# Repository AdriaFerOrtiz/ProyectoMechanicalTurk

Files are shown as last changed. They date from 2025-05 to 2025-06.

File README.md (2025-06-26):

# MechanicalTurk  
*A modern robotic chess player inspired by the historical "Mechanical Turk," combining computer vision, cloud-based AI, and precision robotics to play chess autonomously.*  

---

## 🎯 Project Description  
**MechanicalTurk-ChessRobot** is an autonomous chess-playing robot that bridges physical and digital gameplay. It uses a **cartesian robotic system** to move pieces on a physical board, guided by:  
- **Computer Vision**: Detects piece positions via a camera.  
- **Cloud AI**: Leverages Stockfish or Leela Chess Zero for move calculations.  
- **Precision Robotics**: Moves pieces magnetically from beneath the board.  

**Key Features**:  
- Plays against humans or acts as a physical proxy for online games.  
- Handles edge cases like **obstacle avoidance** (e.g., moving blocking pieces temporarily).  
- **Web interface** to play remotely (like Chess.com but with a real robot).  

**Example Scenario**:  
> A user makes a move on the physical board → The robot’s camera captures the move → Cloud AI calculates the best response → The robot moves the piece by performing the movement intended by the AI.  

---

## 📽️ Demo  

[Video of the robot in action](https://drive.google.com/file/d/1c9VE16P7BDXVjnB_LtAGnboGmgiGng_8/view?usp=drive_link )

---

## 📖 Table of Contents  
1. [Installation](#installation)
   - [Google Cloud Plataform (GCP)](#-1-google-cloud-platform-gcp)
   - [Local Robot Sofrware](#2-local-software)
2. [Electrical Wiring Diagram](#electrical-wiring-diagram)
3. [Components](#components)  
4. [Hardware Design](#hardware-design)  
5. [Software Architecture](#software-architecture)  
   - [Cloud Infrastructure (Google Cloud)](#1-cloud-infrastructure-google-cloud)  
   - [Local Robot Software](#-2-local-robot-software)
   - [Chessboard and Piece Recognition Using Computer Vision](#3-chessboard-and-piece-recognition-using-computer-vision)
6. [3D components](#3d-components)  
7. [Contributions](#amazing-contributions)  
8. [Authors](#authors)  

---

## Installation

This project is composed of two main components:

1. 🌐 The **Google Cloud** infrastructure, which handles vision and chess engine logic.
2. 🤖 The **local robot software**, which controls physical movements and logic.

---

### 🌐 1. Google Cloud Platform (GCP)

#### 📁 Project structure

In the `Google-Cloud/` directory, you will find:

* `chessboard_model/`: (Not required for installation) Training code for the original vision model.
* `chessboard_visual_function/`: Code used in the **Cloud Function** for detecting the board and pieces from an image.
* `chessboard_web/`: Frontend code and Firebase project. Contains:

  * `public/`: The web app (`index.html`, `script.js`, `styles.css`).
* `stockfish_cloud_run/`: Code for deploying **Stockfish** to **Cloud Run**.

#### ☁️ Google Cloud Setup

Make sure you have the Google Cloud CLI installed and authenticated:

```bash
gcloud auth login
gcloud config set project [YOUR_PROJECT_ID]
```

##### 🔸 Deploy the Vision Cloud Function

Go to the folder:

```bash
cd Google-Cloud/chessboard_visual_function
```

Deploy the function:

```bash
gcloud functions deploy predict_chessboard \
  --runtime python310 \
  --trigger-http \
  --allow-unauthenticated \
  --region europe-southwest1 \
  --entry-point predict_chessboard
```

##### 🔸 Deploy Stockfish on Cloud Run

From the folder:

```bash
cd Google-Cloud/stockfish_cloud_run
```

Deploy with:

```bash
gcloud run deploy stockfish-service \
  --source . \
  --allow-unauthenticated \
  --region europe-west1
```

##### 🔸 Web Setup (Firebase Hosting)

You can test the web from the `public/` folder using any static server:

```bash
cd Google-Cloud/chessboard_web/public
python3 -m http.server 8000
# Or open index.html manually in your browser
```

If you have Firebase CLI configured and wish to deploy:

```bash
cd Google-Cloud/chessboard_web
firebase deploy
```

> ⚠️ Remember to update the endpoints in `script.js` with your actual deployed URLs for:
>
> * `predict_chessboard`
> * `stockfish-service`

---

### 2. Local Software

#### 📁 Project location

The local code is in the `src/` folder and includes:

* `modulo_central.py`: Handles logic and piece coordination.
* `motor_control.py`: Translates paths into robot movement commands.
* `game_state.py`: Board representation and utilities.
* `conexion_web.py`: A simulated Flask server to receive move commands.

#### ✅ Requirements

Since there's no `requirements.txt`, you can install the necessary packages with:

```bash
pip install flask flask-cors requests serial
```

If needed, here’s a `requirements.txt` you can create inside `src/`:

```txt
flask
flask-cors
requests
serial
```

#### 🚀 Running the robot server

Launch the Flask server to allow robot communication:

```bash
cd src
python conexion_web.py
```

This server listens on port `5000` and logs moves received from the web interface.

---
## Electrical Wiring Diagram

The following diagram illustrates the complete wiring of the robot's electronic components, including the Arduino, stepper drivers, relays, power supply, and camera system:

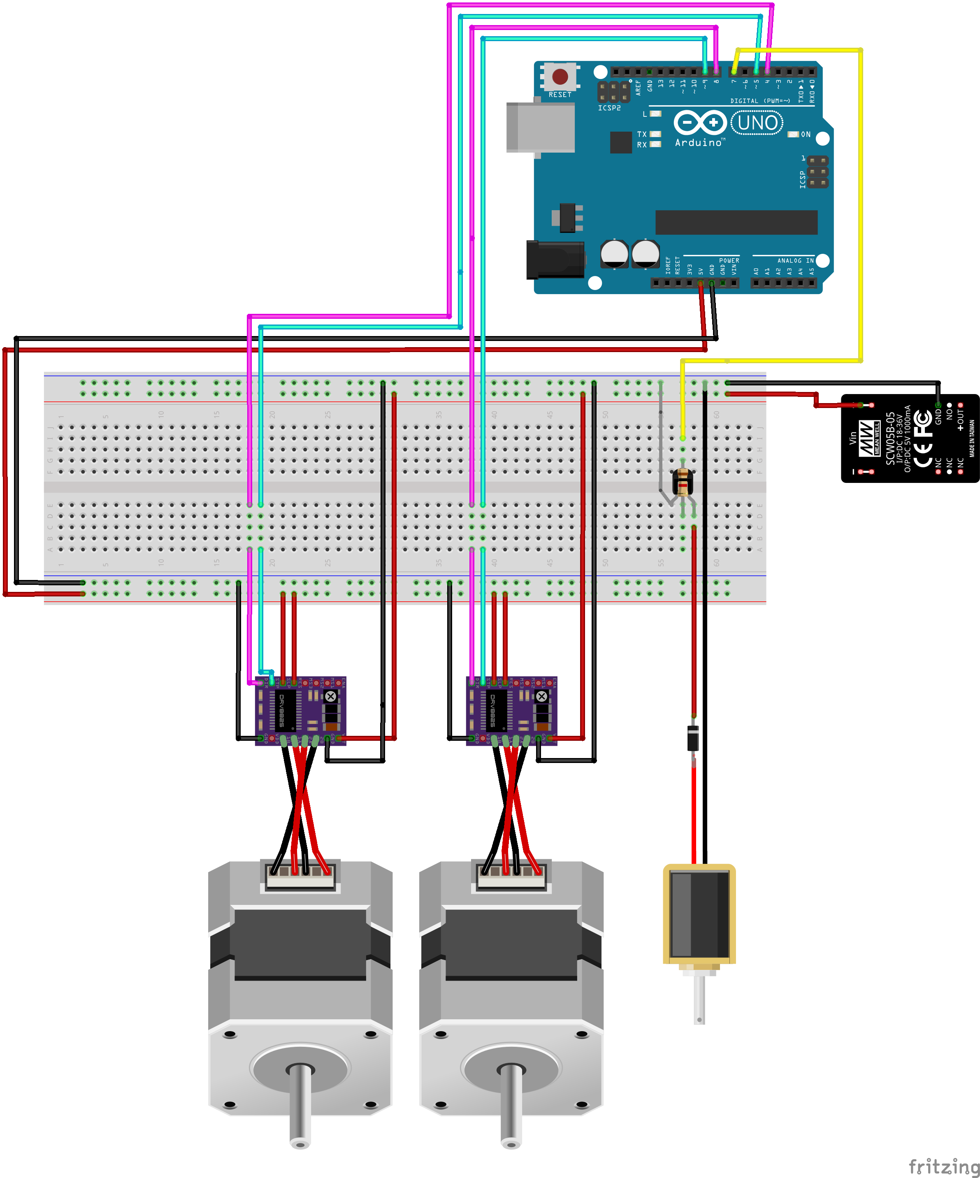
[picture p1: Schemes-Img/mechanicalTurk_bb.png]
Wiring Diagram


## Components
| Componente | Imagen | Enlace |
|---|---|---|
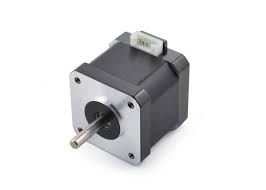
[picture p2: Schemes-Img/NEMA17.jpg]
NEMA17
| **Motor NEMA 17 / 3.5 Kg** |  | [Bricogeek](https://tienda.bricogeek.com/motores-paso-a-paso/1360-motor-nema-17-35kg-con-conector-y-cable.html) |
| **Arduino Uno** | Arduino Uno | [Arduino.cc](https://store.arduino.cc/products/arduino-uno-rev3) |
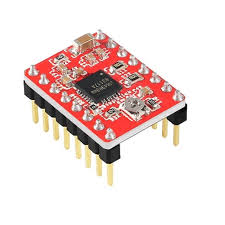
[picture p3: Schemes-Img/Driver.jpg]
A4988
| **Driver A4988** |  | [Pololu](https://www.pololu.com/product/1182) |
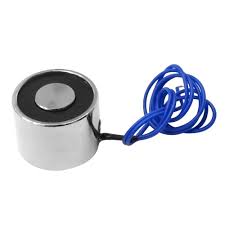
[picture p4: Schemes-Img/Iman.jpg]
12V Electroimán
| **Electroimán 12 V / 100 N** |  | [TodoElectrónica](https://www.todoelectronica.com/modulo-rele-5vdc-de-1-canal-10a-para-arduino-p-110226.html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)  |
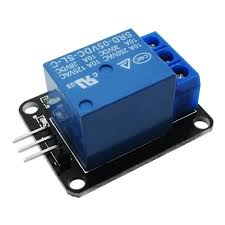
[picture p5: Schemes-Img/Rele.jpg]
Relé 5V 10A
| **Relé 5 V 10 A** |  | [Amazon](https://www.amazon.com/10A-Channel-Relay-Module-Arduino/dp/B07Z432CS3) |
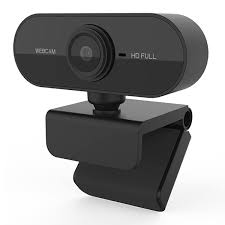
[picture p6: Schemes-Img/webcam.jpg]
Webcam Genérica
| **Webcam USB Genérica (720p/1080p)** |  | [Amazon – Webcam USB 1080p con micrófono](https://www.amazon.com/-/es/Webcam-Computadora-Micrófono-Resolución-Streaming/dp/B08HRPDYTP) |
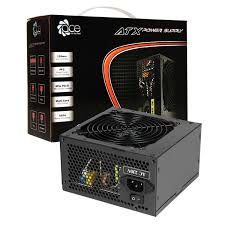
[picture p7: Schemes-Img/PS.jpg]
ATX PSU
| **ATX 500W Power Supply** |  | [PCComponentes (similar)](https://www.pccomponentes.com/fuentes-de-alimentacion) |
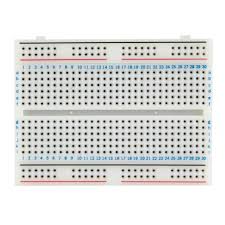
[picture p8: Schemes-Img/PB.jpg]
ProtoBoard
| **456 Point Breadboard** |  | [Amazon](https://www.amazon.com/EL-CP-003-Breadboard-Distribution-Solderless-Prototyping/dp/B01EV6LJ7G) |

**Software**:  
- **Google Cloud Vision** (Computer vision)  
- **Stockfish 16** (Chess engine)  
- **FastAPI** (Web interface backend)  

---

## Hardware Design
*Cartesian robot design.*  

Hardware movement gif

---

## Software Architecture

### 1. Cloud Infrastructure (Google Cloud)

This project leverages **Google Cloud Platform (GCP)** to handle compute-intensive tasks such as board recognition and AI move generation. The cloud infrastructure is composed of two key services:

#### 🔍 Cloud Function: Board Recognition

A **Cloud Function** receives chessboard images captured via webcam or uploaded through the web interface. These images are processed using a trained machine learning model (TensorFlow or PyTorch), and the function returns a board state encoded as an 8x8 matrix in FEN-like notation.

* **Input:** JPEG or PNG image of the board
* **Output:** JSON object containing the current board state

#### ♟️ Cloud Run: Stockfish

A **Cloud Run** container hosts a persistent instance of the **Stockfish chess engine**. It takes the current board state and returns:

* The best move according to Stockfish (UCI notation)
* The evaluation score of the position (e.g., `+0.8`, `Mate in 2`)

#### 🌐 Web-to-Cloud Communication

The frontend web app communicates with these cloud services:

* Image uploads → sent to the Vision Cloud Function
* Board state → sent to the Stockfish Cloud Run service

#### 🖥️ Web Interface Overview

The web application acts as the **central control panel** for the system. It provides:

* Upload and processing of board images
* A real-time digital rendering of the chessboard
* The ability to play against another human or Stockfish
* Visualization of Stockfish evaluations and suggested moves
* Communication with the robot via HTTP

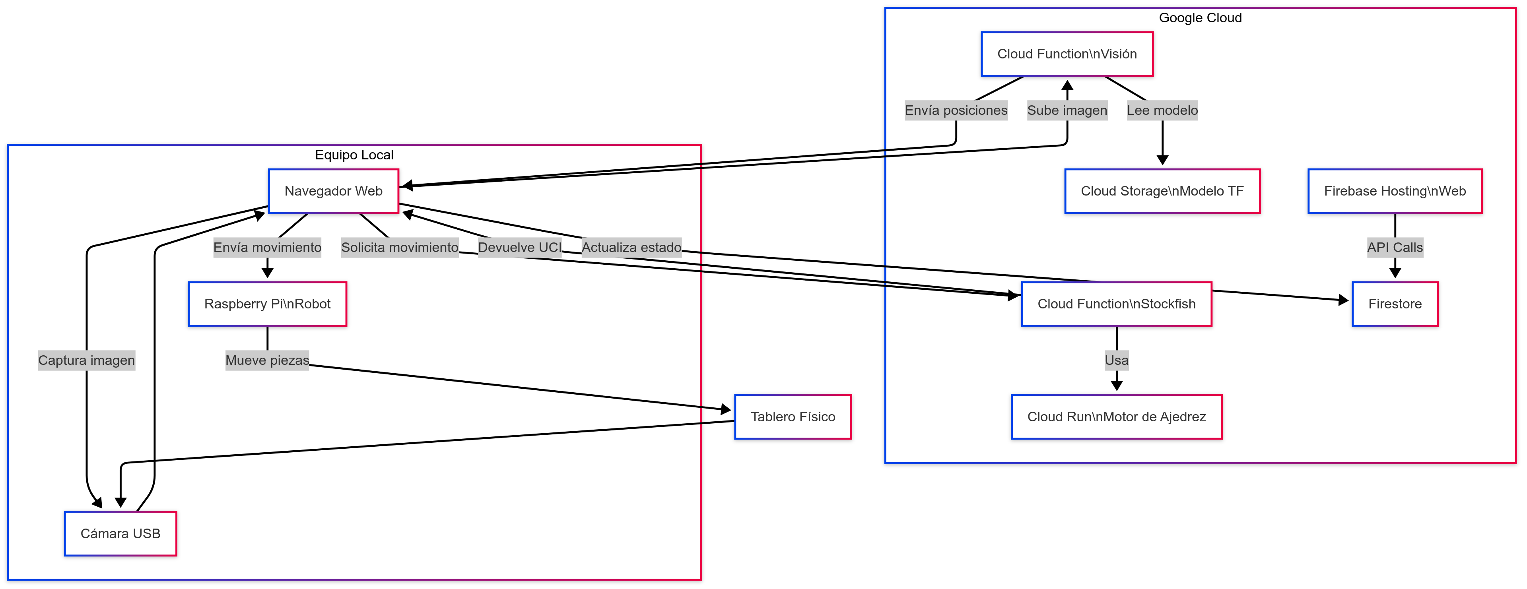
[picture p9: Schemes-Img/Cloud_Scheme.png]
Cloud Diagram


---

### 🤖 2. Local Robot Software

The robot’s local software is responsible for interpreting commands from the web interface and executing the necessary mechanical movements. It is modular and divided into several blocks, each with a specific role.

#### 🧩 Local System Architecture (Modules Overview)

| Block | Description |
| --- | --- |
| **Server (API Listener)** | Listens for HTTP POST requests from the web interface. Extracts the move and forwards it to the Central Module. |
| **Central Module** | Orchestrates the logic: processes the move, checks for obstacles, resolves pathfinding, and delegates to the motor control module. |
| **Game State Manager** | Stores and updates the internal state of the chessboard. Translates algebraic coordinates into grid positions. |
| **Pathfinding & Obstacle Handler** | Detects if a piece is blocked and calculates alternative paths. Can temporarily move blocking pieces, execute the main move, and then restore the original state. |
| **Motor Control** | Translates sequences of square coordinates into physical instructions (`w`, `a`, `s`, `d`) that the robot understands and executes. |

#### 🔄 Local Software Diagram

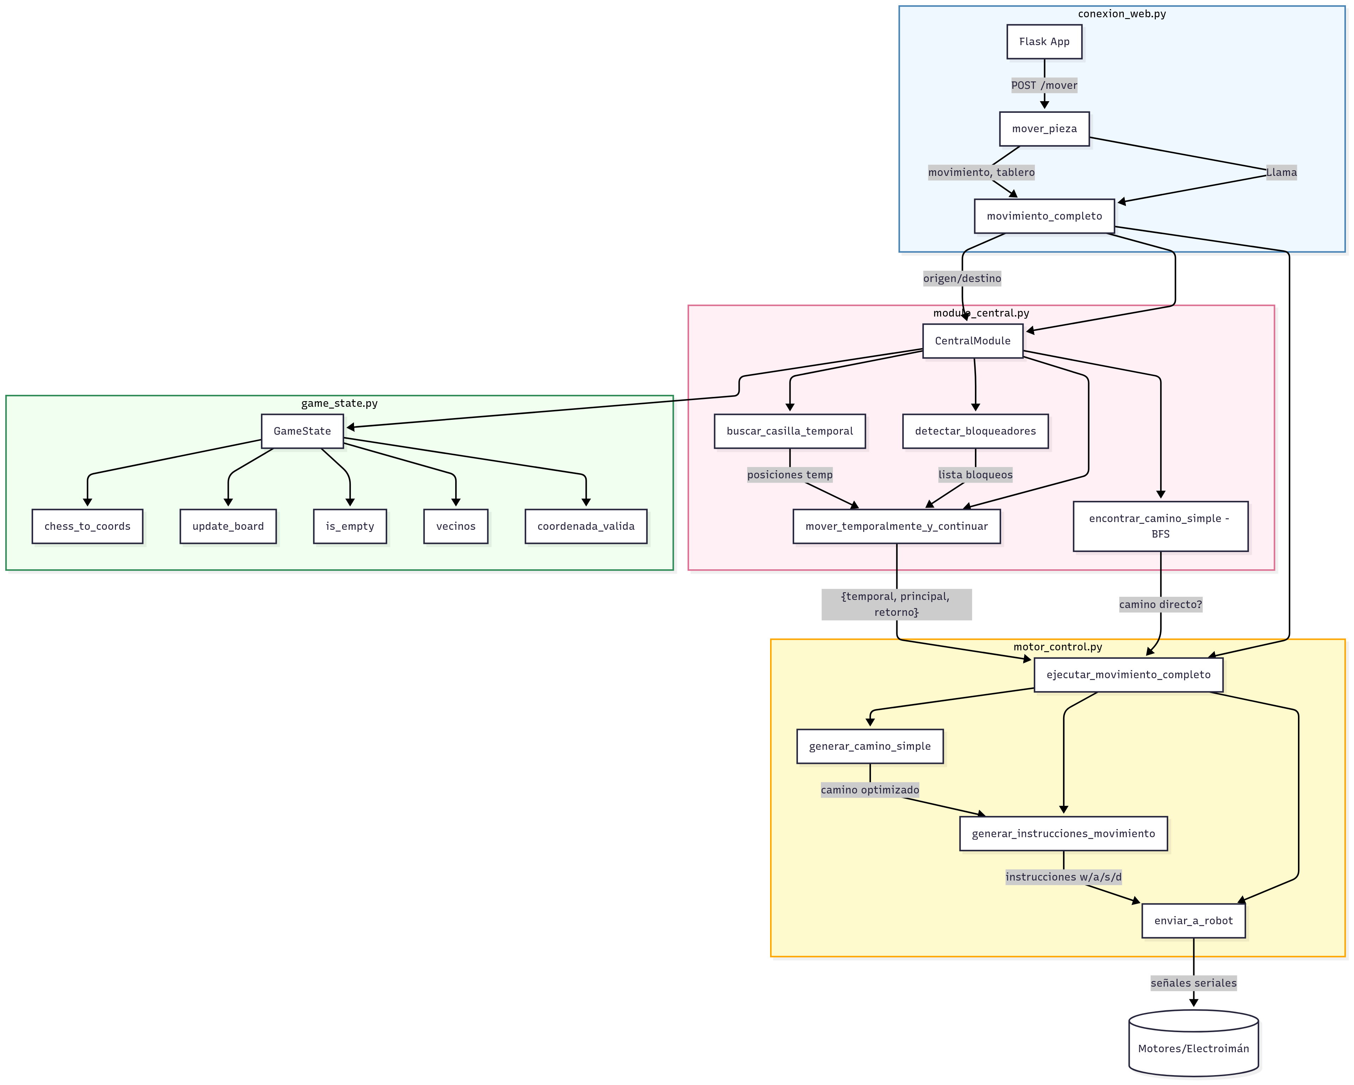
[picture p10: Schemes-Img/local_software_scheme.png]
Local Software Diagram


#### 🛠️ Execution Flow Summary

1. The web sends a POST request with the move and current board state.
2. The server receives the request and passes it to the `CentralModule`.
3. The central logic:

   * Validates the move
   * Checks for blockers
   * Moves the blocker temporarily if necessary
   * Executes the desired move
   * Restores any displaced pieces
4. The motor controller receives movement paths and emits sequential movement signals to the robot (via simulated or actual hardware).

---

### 3. Chessboard and Piece Recognition Using Computer Vision

---

#### 1. Introduction

This project is part of a broader initiative to build a fully autonomous chess-playing robot. Our contribution focuses on the vision system, which identifies the real-time state of a physical chessboard via an overhead camera.

We employed image processing and deep learning techniques to detect the board, segment the squares, and classify pieces, converting the results into algebraic notation for robotic interpretation. The system is designed to be robust against lighting variations, board styles, and camera perspectives.

---

#### 2. Related Work

Prior research explored digitizing chessboards using computer vision. A project at the Universidad Politécnica de Madrid applied an Xception network with perspective transforms, achieving 98% accuracy in piece recognition. Stanford proposed combining shape descriptors with the Hough transform to recognize boards from angled views, achieving 70–100% accuracy depending on the viewpoint.

Commercial apps like ChessEye and Chessify use CNNs on mobile devices to recognize physical or digital boards, integrating engines like Stockfish or Leela Chess Zero. These approaches demonstrate that vision-based systems are viable alternatives to sensor-based boards such as those from DGT or Novag.

---

#### 3. System Overview

The system is based on a CNN trained on a custom dataset of manually captured and labeled chessboard images.

#### Processing Pipeline:
1. **Image Capture**
3. **Board Detection and Square Segmentation**
4. **Square-wise Filtering**
5. **CNN-based Classification**
6. **Translation to Algebraic Notation**

The entire process runs in a cloud function that receives an image and returns an 8x8 matrix of recognized positions. The system’s accuracy has been validated per square and per piece type, confirming its feasibility for robotic integration.

---

#### 4. Experiments and Results

##### 4.1 Initial Approach

An overhead image was captured, converted to grayscale, and processed using the Canny edge detector to identify board lines. However, line intersections were inconsistent, leading to incorrect segmentation and failure to isolate all 64 squares. Issues included uneven lighting and imprecise line detection.

##### 4.2 Improved Board Segmentation

We introduced green corner markers on the board to aid square segmentation. These markers enabled reliable detection of board corners, and the board was successfully divided into 64 square images.

Data augmentation was applied to each square (rotations, contrast adjustment) to simulate various conditions. A single model was trained to classify the piece type in each square. However, due to dataset imbalance (many pawns and empty squares), early results were misleadingly high. Normalizing the dataset dropped accuracy to ~60%.

Square segmentation still had occasional misalignments, which affected classification. These issues led to a refined, modular approach for the final system.

---

#### 4.3 Final Version

##### 4.3.1 Concept

A modular system was implemented with three independent models:
- **Presence Model**: Detects if a piece exists in the square.
- **Color Model**: Classifies the piece as white or black.
- **Type Model**: Identifies the piece type (Pawn, Knight, Bishop, Rook, Queen, King).

**Test-Time Augmentation (TTA)** is used to increase reliability: each square is augmented with rotations, flips, and filters, and the final prediction is averaged across all augmentations.

##### 4.3.2 Procedure

**Board Segmentation**  
The `crop_and_divide_board` function uses green markers to accurately crop the board into 64 squares. A margin parameter ensures square-centered cropping.

<h4>Step-by-Step Image Processing Pipeline</h4>

<table>
  <tr>
    <th>Step</th>
    <th>Image</th>
    <th>Description</th>
  </tr>

  <tr>
    <td><strong>1. Original Image</strong></td>
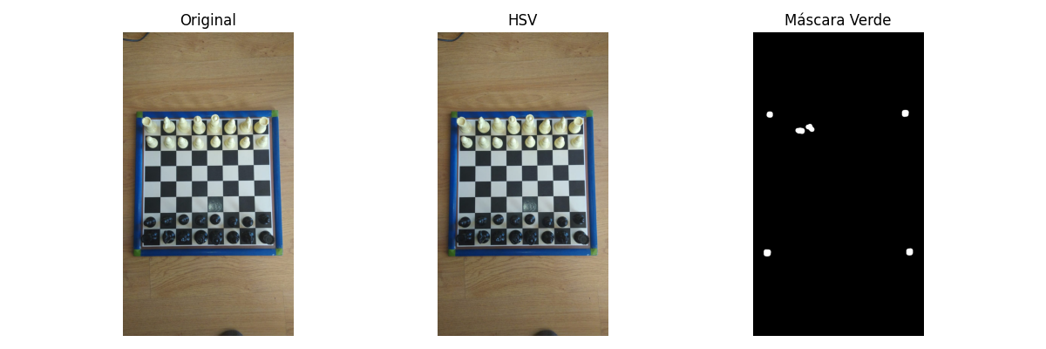
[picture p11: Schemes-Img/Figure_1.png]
    <td></td>
    <td>The input image as captured from the camera. It shows the chessboard including the green corner markers.</td>
  </tr>

  <tr>
    <td><strong>2. HSV Conversion</strong></td>
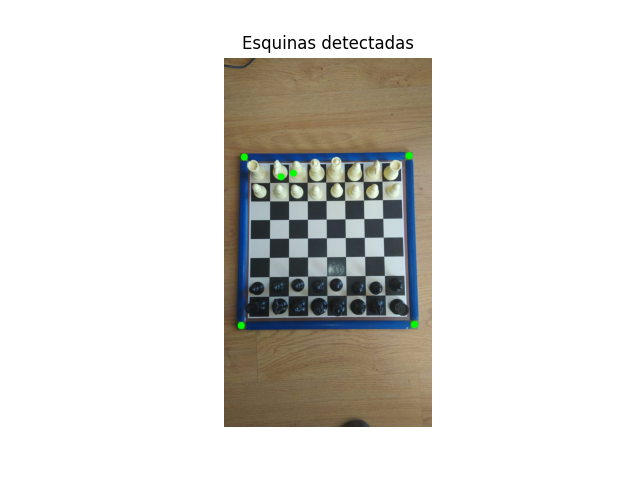
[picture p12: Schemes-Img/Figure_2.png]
    <td></td>
    <td>The image converted to HSV color space, which is more suitable for color filtering (used to detect green markers).</td>
  </tr>

  <tr>
    <td><strong>3. Green Mask</strong></td>
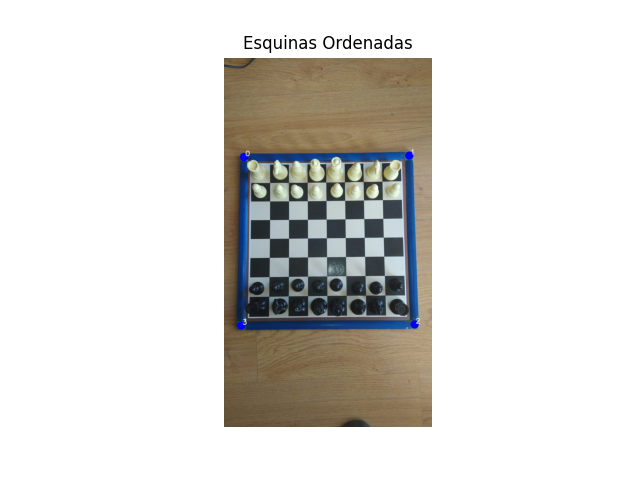
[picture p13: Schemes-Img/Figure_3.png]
    <td></td>
    <td>A binary mask that highlights areas with green color based on a defined HSV range. This helps isolate the board corners.</td>
  </tr>

  <tr>
    <td><strong>4. Corner Detection</strong></td>
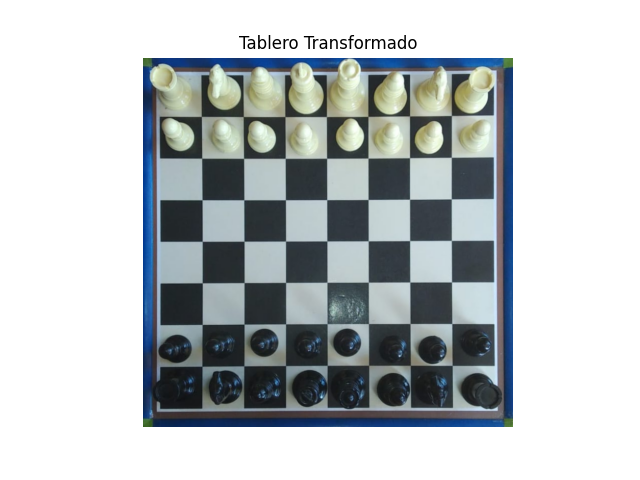
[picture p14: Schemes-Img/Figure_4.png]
    <td></td>
    <td>Green circular blobs are detected as corners using contour filtering and centroid extraction. These are used to define the board's geometry.</td>
  </tr>

  <tr>
    <td><strong>5. Ordered Corners</strong></td>
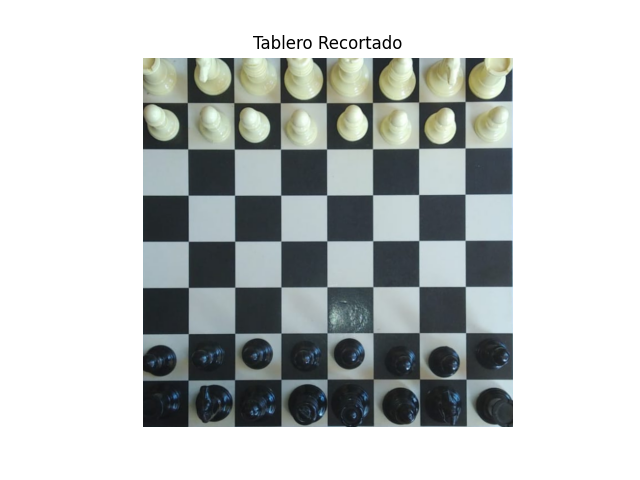
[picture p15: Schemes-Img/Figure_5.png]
    <td></td>
    <td>The detected corners are reordered to follow a consistent pattern: top-left, top-right, bottom-right, bottom-left. This is critical for perspective correction.</td>
  </tr>

  <tr>
    <td><strong>6. Perspective Correction</strong></td>
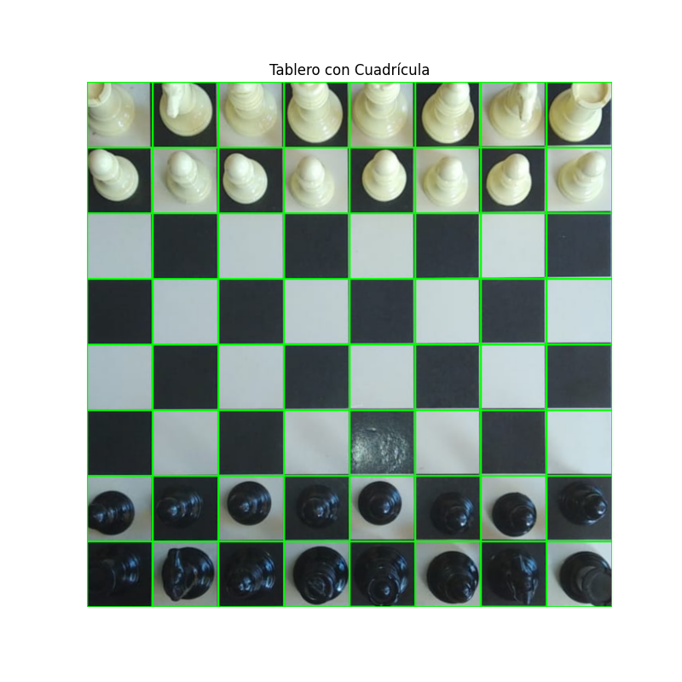
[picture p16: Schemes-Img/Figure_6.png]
    <td></td>
    <td>The chessboard is warped into a square using a perspective transform. This produces a flat, aligned top-down view of the board.</td>
  </tr>

  <tr>
    <td><strong>7. Board Grid Division</strong></td>
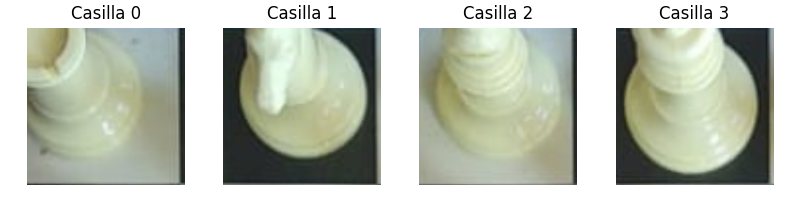
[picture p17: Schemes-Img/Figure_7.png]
    <td></td>
    <td>The aligned board is divided into an 8x8 grid, generating 64 individual cell images. These are used for per-square analysis and classification.</td>
  </tr>

</table>

**Test-Time Augmentation (TTA)**  
Each square is augmented by:
- Rotations (90°, 180°, 270°)
- Flips (horizontal/vertical)
- Filters (contrast, gradient, etc.)

| Filter | Image |
|---|---|
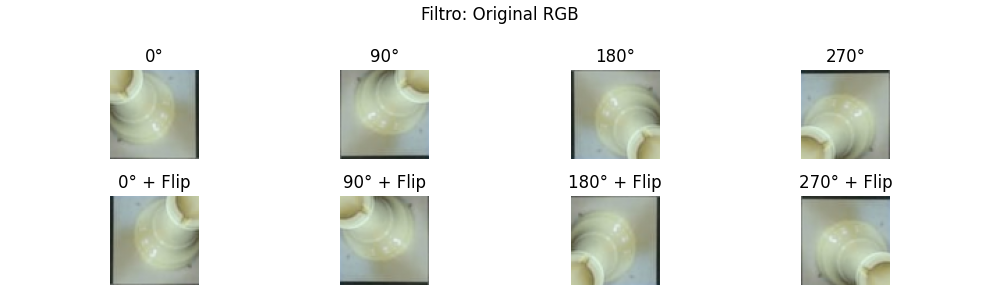
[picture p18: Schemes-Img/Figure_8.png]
| **Filter1** |  |
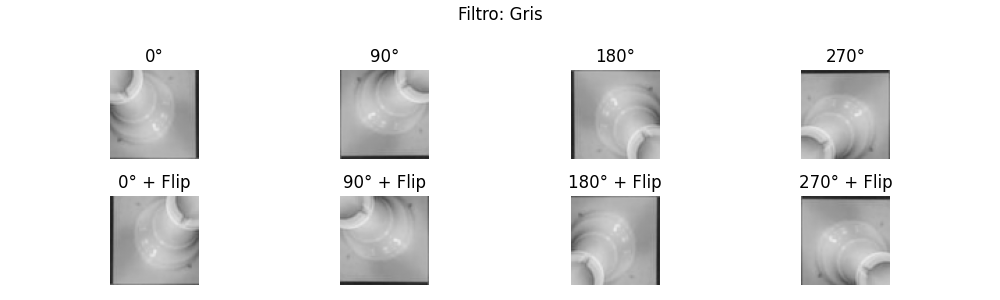
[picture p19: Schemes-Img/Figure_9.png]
| **Filter2** |  |
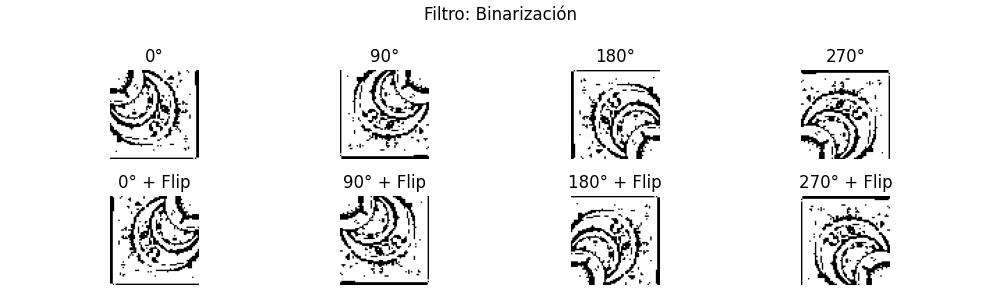
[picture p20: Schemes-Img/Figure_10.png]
| **Filter3** |  |
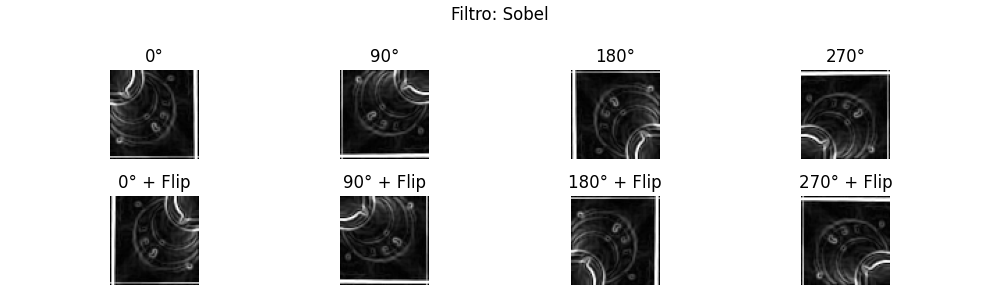
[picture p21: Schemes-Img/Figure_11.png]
| **Filter4** |  |
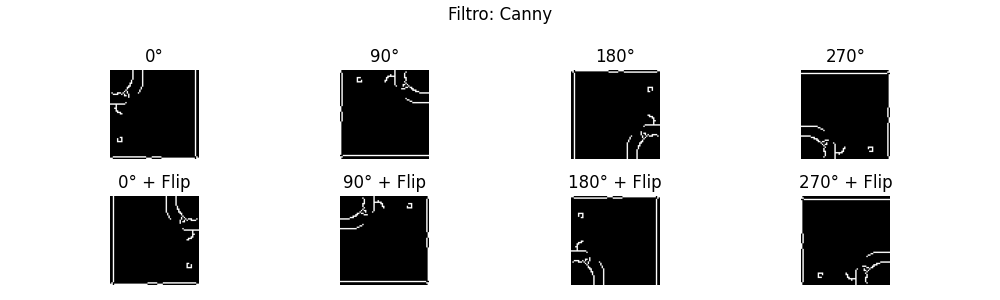
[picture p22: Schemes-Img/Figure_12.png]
| **Filter5** |  |

**Specialized Model Inference**  
Each augmented square is processed through:
- **Presence Model** (binary classification)
- **Color Model** (binary classification: white or black)
- **Type Model** (multi-class: P, N, B, R, Q, K)

Predictions are averaged across augmentations. If the presence score > 0.5, a piece is assumed. Color and type are only predicted when a piece is present.

**Integration of Results**  
Three boards are created:
- **Presence Board**: marks squares with X or .
- **Color Board**: marks squares with B, N or .
- **Piece Board**: marks squares with piece letters (e.g., 'p', 'K', or '.').

---

##### 4.3.3 Quantitative Results

**Presence Model**  
- Accuracy: >99%
- F1-Score: 0.994

**Color Model**  
- Accuracy: >98%
- F1-Score: 0.987

**Type Model**  
- Accuracy: ~90%
- Best results: Knights and Kings
- Most confusion: Pawns vs Bishops

| Class | Precision | Recall | F1-Score |
|---|---|---|---|
| P | 0.900 | 0.871  | 0.885 |
| N | 0.915 | 0.925  | 0.920 |
| B | 0.860 | 0.893  | 0.876 |
| R | 0.922 | 0.898  | 0.910 |
| Q | 0.916 | 0.888  | 0.902 |
| K | 0.897 | 0.926  | 0.911 |

---

##### 4.3.4 Insights

- **Robustness**: TTA improves prediction consistency under visual noise.
- **Modularity**: Independent models enhance flexibility and debugging.
- **Limitations**: System performance drops if the board is misaligned or highly unlit/unusual in style.

---

#### 5. Conclusion

We successfully developed a modular computer vision system capable of reconstructing a chessboard's state from a single image. The multi-stage design combined deep learning, data augmentation, and precise segmentation to achieve high accuracy even under uncontrolled conditions.

##### Future Work:
- Automatic board detection in cluttered scenes
- Handling blurred pieces, reflections, and extreme lighting
- Extension to video-based real-time chess tracking

This project demonstrates the feasibility of high-fidelity chessboard state reconstruction and opens paths for future applications in robotics, game analysis, and education.

---
## 3D Components

### Components List

**1. Axis (4 pieces)**

*  **Description**: Axes that allow movement along the X and Y axes.
*  **Dimensions**:
     * Length: 20 cm
       
     * Width: 5.2 cm
       
     * Height: 6.5 cm
       
*  **File**: axis.stl
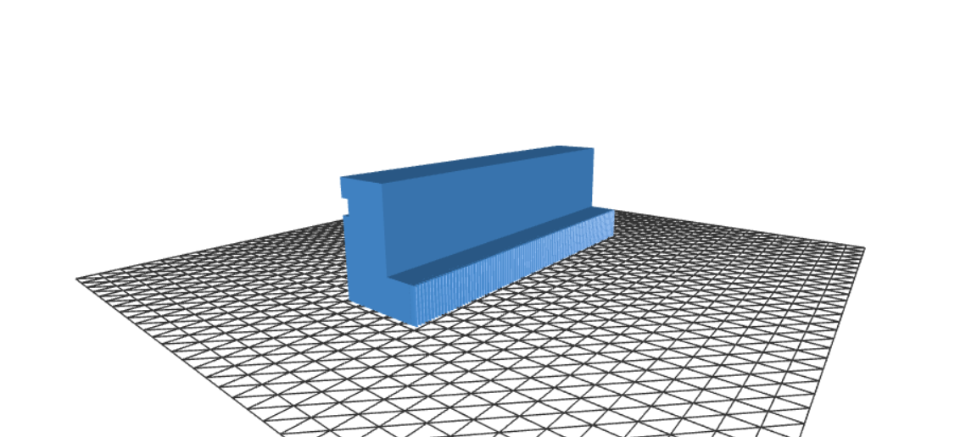
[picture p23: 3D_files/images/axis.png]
Axis Preview


**2. Box**

*  **Description**: Box where all the robot's mechanism is
*  **Dimensions**:
     * Length: 45 cm
       
     * Width: 45 cm
       
     * Height: 20 cm
       
*  **File**: box.svg
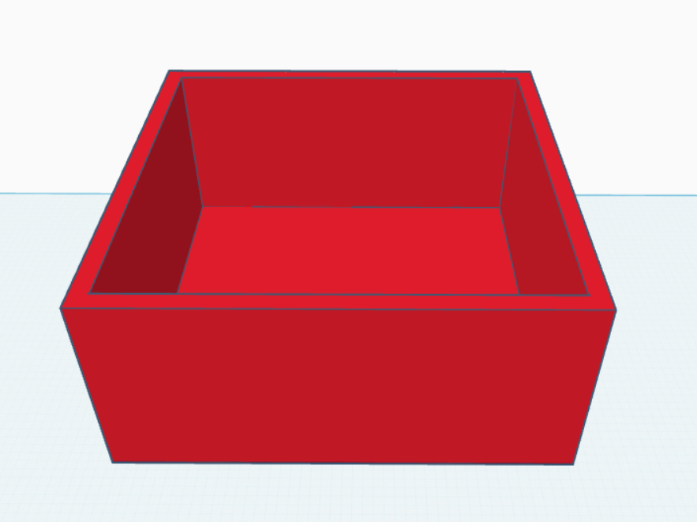
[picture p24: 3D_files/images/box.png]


**3. Box_lid**

*  **Description**: Lid of the box where the chessboard is painted
*  **Dimensions**:
     * Length: 45 cm
       
     * Width: 45 cm
       
     * Height: 0.6 cm
       
*  **File**: box_lid.stl
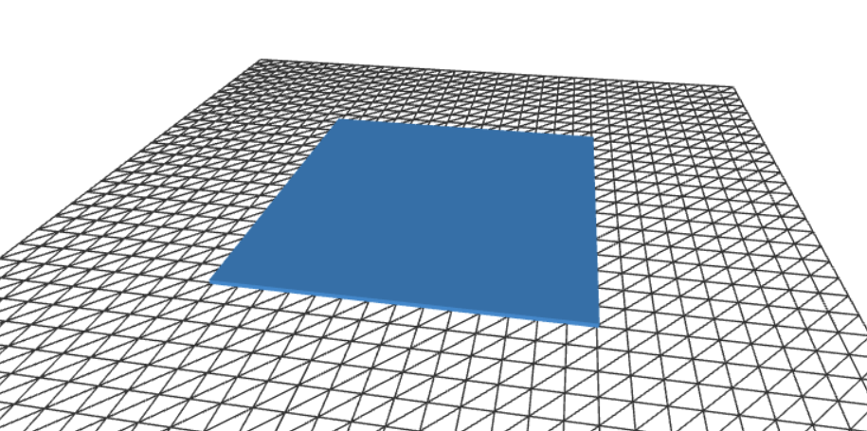
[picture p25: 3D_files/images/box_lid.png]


**4. Cylinders (2 pieces)**

*  **Description**: Support cylinders for the movement of the axis.
*  **Dimensions**:
     * Length: 0.8 cm
       
     * Width: 0.8 cm
       
     * Height: 3 cm
       
*  **File**: cylinder.stl
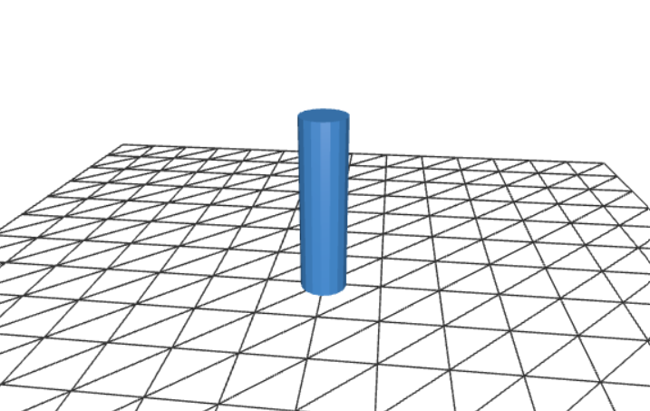
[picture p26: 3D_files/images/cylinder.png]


**5. Lid_brace**

*  **Description**: Lace piece for the box lid.
*  **Dimensions**:
     * Length: 42 cm
       
     * Width: 42 cm
       
     * Height: 1 cm
       
*  **File**: lid_brace.stl
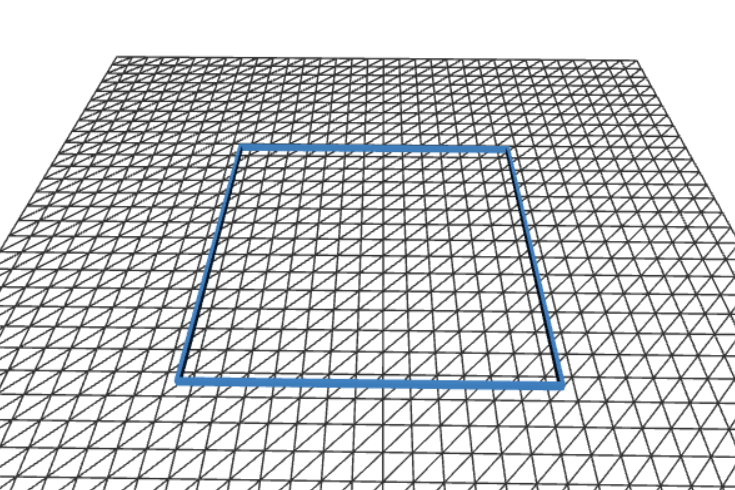
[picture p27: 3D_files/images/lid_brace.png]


**6. Platform (2 pieces)**

*  **Description**: Platform to move the electromagnet around the chessboard.
*  **Dimensions**:
     * Length: 12 cm
       
     * Width: 5.7 cm
       
     * Height: 1 cm
       
*  **File**: platform.stl
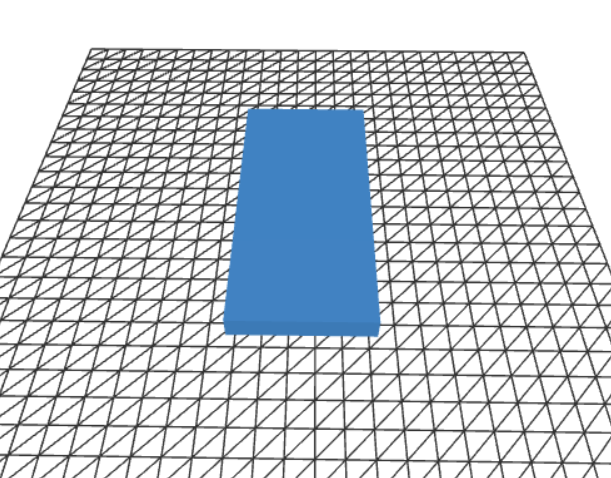
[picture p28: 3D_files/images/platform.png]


**7. Toothed_cylinders (2 pieces)**

*  **Description**: Toothed cylinders to move along the axes.
*  **Dimensions**:
     * Length: 0.9 cm
       
     * Width: 0.9 cm
       
     * Height: 1.5 cm
       
*  **File**: toothed_cylinders.stl
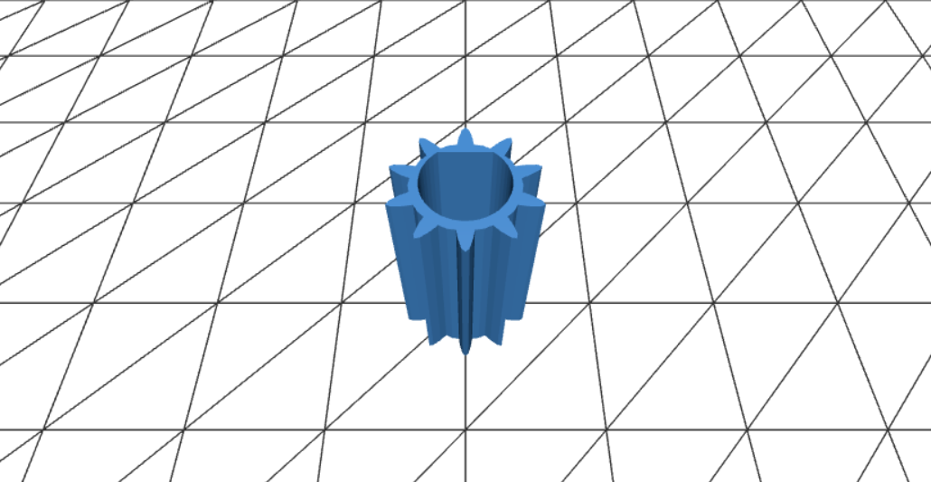
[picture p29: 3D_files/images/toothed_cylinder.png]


### Summary Table

| # | Component | Pieces | File |
|---|---|---|---|
| 1 | Axis | 4 | axis.stl |
| 2 | Box | 1 | box.stl |
| 3 | Box Lid | 1 | box_lid.stl |
| 4 | Cylinders | 2 | cylinder.stl |
| 5 | Lid Brace | 1 | lid_brace.stl |
| 6 | Platform | 2 | platform.stl |
| 7 | Toothed Cylinders | 2 | toothed_cylinders.stl |

### How to Use the 3D Files

1. **Download**: All STL files are located in the `/3D_files` directory of this repository.
2. **Open**: Use a slicer like [Ultimaker Cura](https://ultimaker.com/software/ultimaker-cura) or [PrusaSlicer](https://www.prusa3d.com/page/prusaslicer_424/) to open the `.stl` files.
3. **Print Settings** (recommended):
   - Layer height: 0.2 mm
   - Infill: 20% – 40%
   - Supports: As needed depending on the piece
   - Material: PLA or PETG

---

## Amazing Contributions  
- **Obstacle Avoidance**: The robot plans alternative paths if pieces block movement.  
- **Low-Cost Precision**: Achieves sub-millimeter accuracy with budget stepper motors.  
- **Social Impact**: Makes chess accessible for visually impaired players via physical interaction.  

---

## Authors  
- Eduard José García Mendeleac
- Adrià Fernández Ortiz
- Luis Adrián Gómez Batista

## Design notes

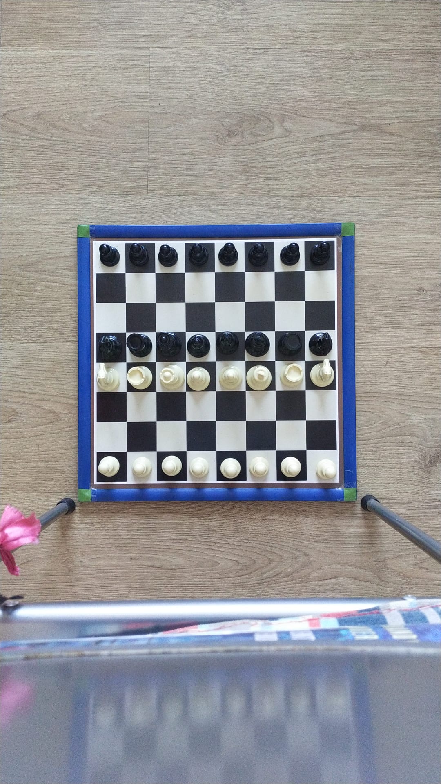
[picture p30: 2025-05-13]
Google-Cloud/chessboard_model/img/board14.jpeg

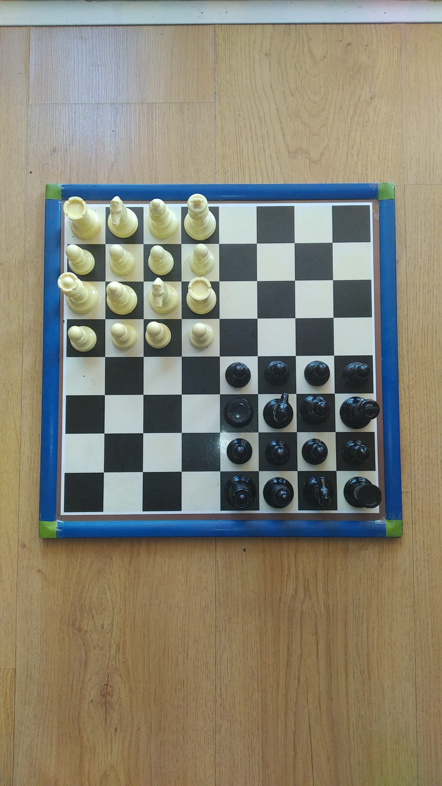
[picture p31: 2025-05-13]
VC/img/board44.jpeg

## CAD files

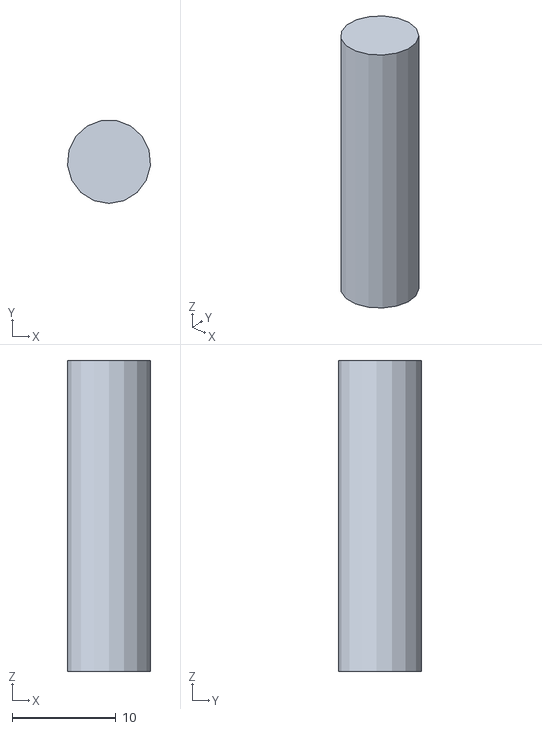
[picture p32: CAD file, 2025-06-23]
3D_files/cylinder.stl
8.00 x 8.00 x 30.0

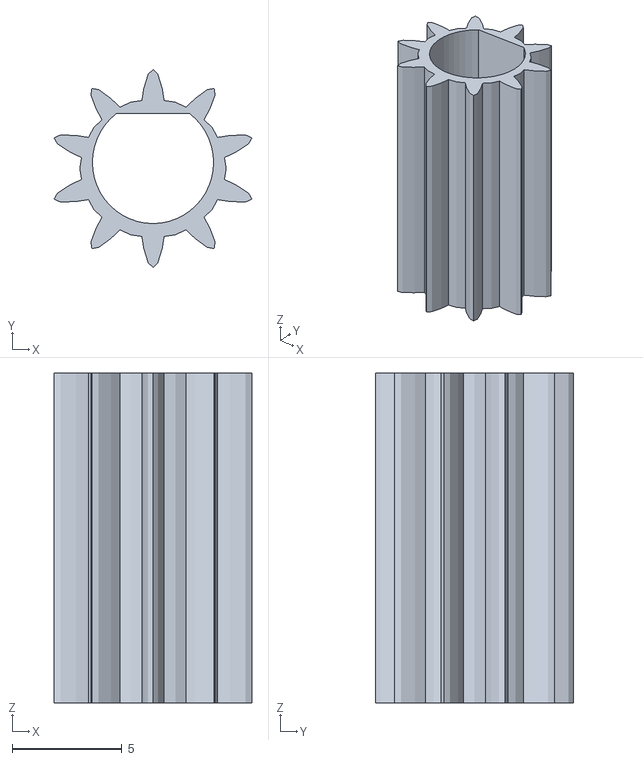
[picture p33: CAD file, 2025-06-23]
3D_files/toothed_cylinders.stl
9.00 x 9.00 x 15.0

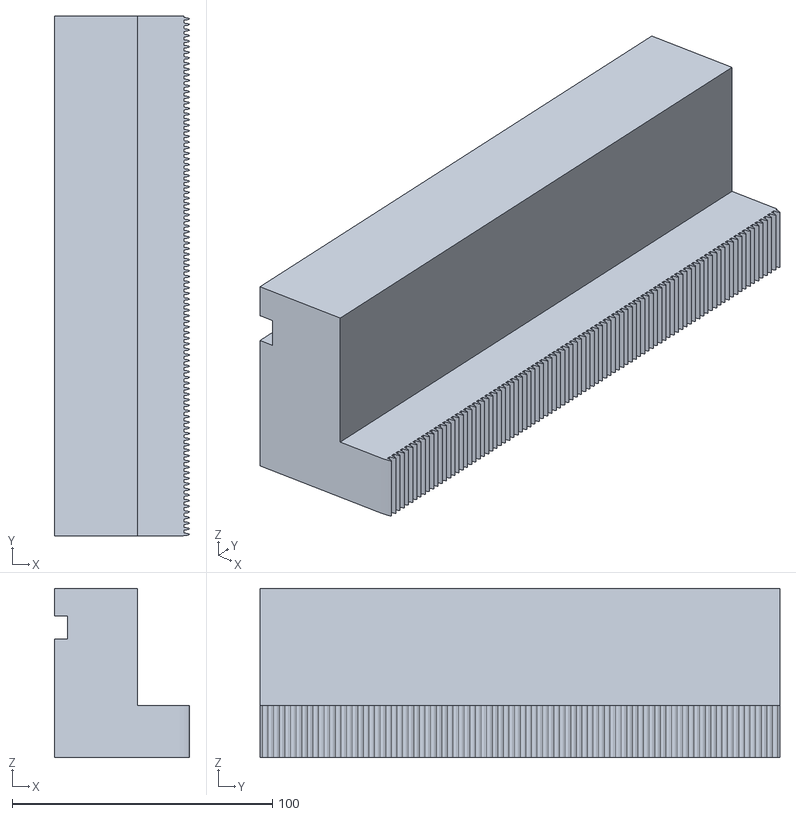
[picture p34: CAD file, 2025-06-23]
3D_files/axis.stl
52.0 x 200.0 x 65.0

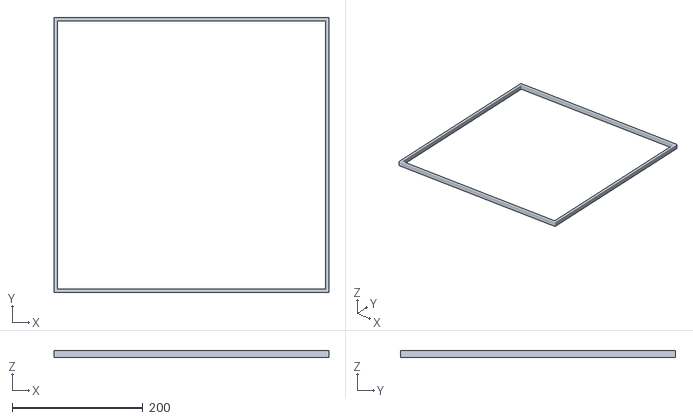
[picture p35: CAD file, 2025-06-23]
3D_files/lid_brace.stl
420.0 x 420.0 x 10.0

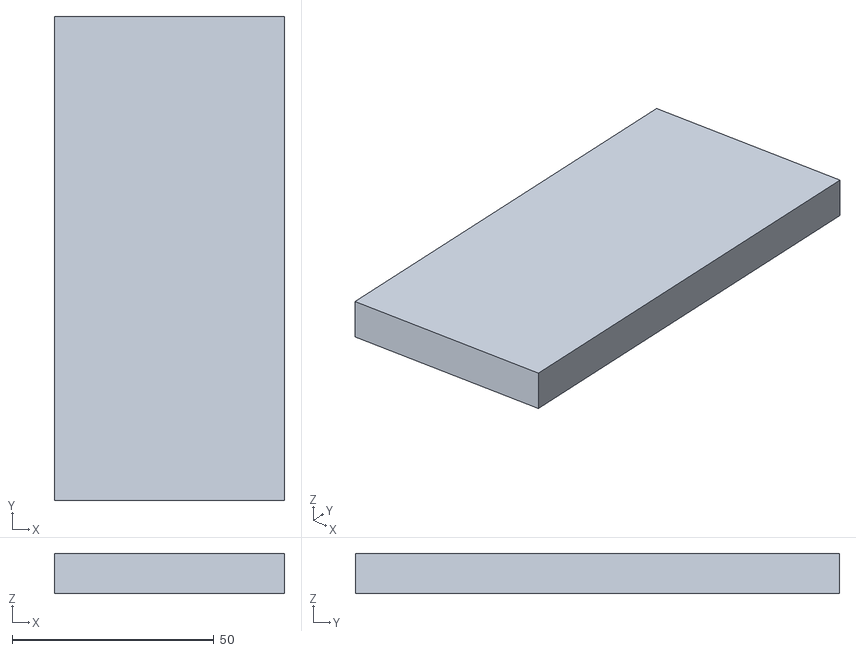
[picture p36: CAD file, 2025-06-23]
3D_files/platform.stl
57.0 x 120.0 x 10.0

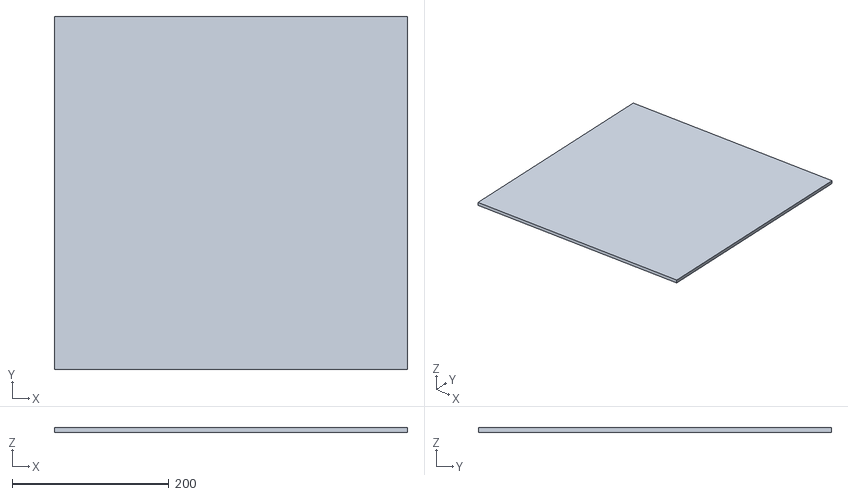
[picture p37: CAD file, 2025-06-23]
3D_files/box_lid.stl
450.0 x 450.0 x 6.00

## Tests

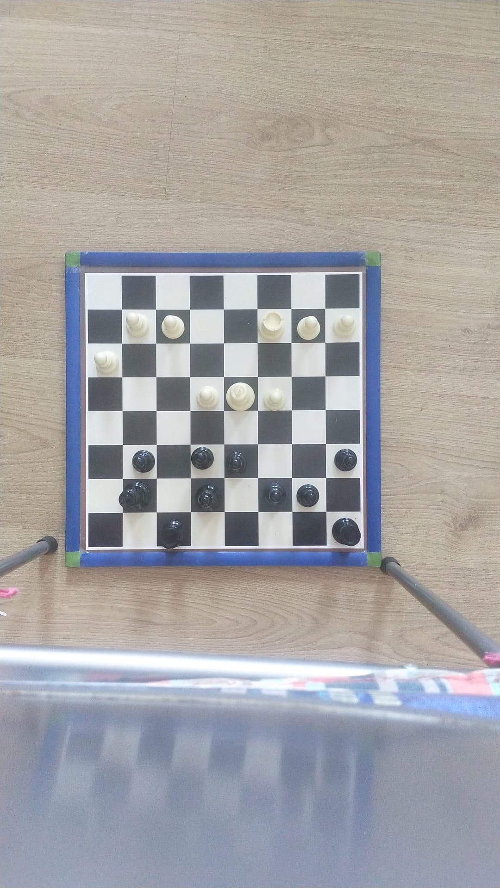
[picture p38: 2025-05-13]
VC/pruebas/prueba (7).jpeg

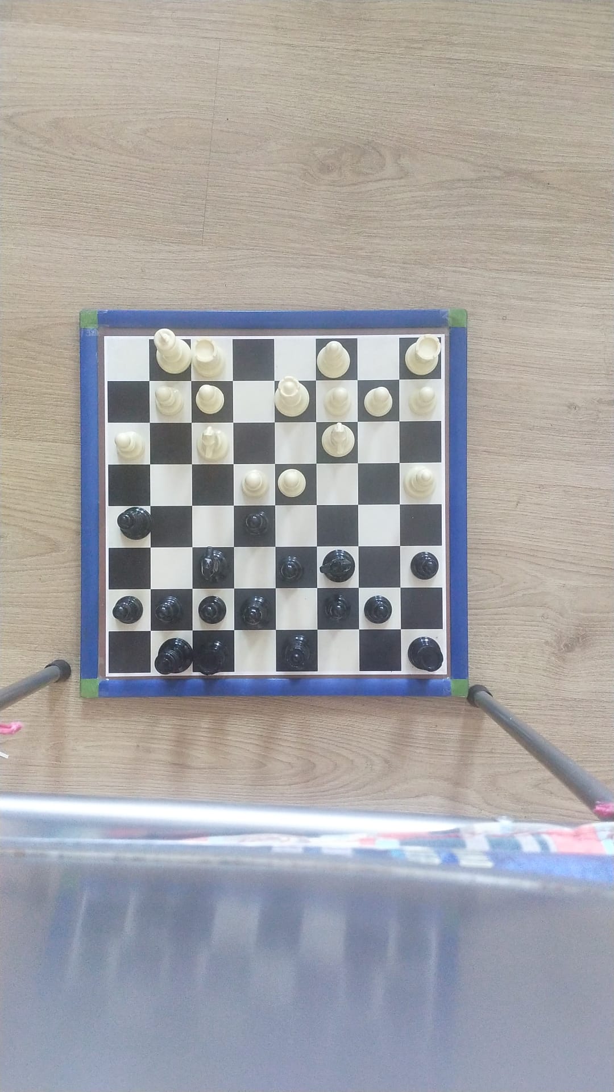
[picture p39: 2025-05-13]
VC/pruebas/prueba (3).jpeg

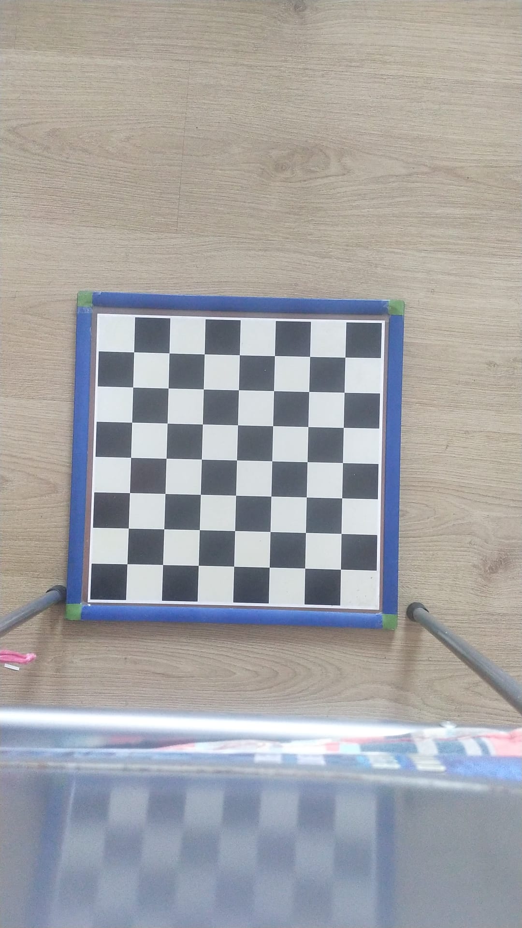
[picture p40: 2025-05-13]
VC/pruebas/prueba (11).jpeg

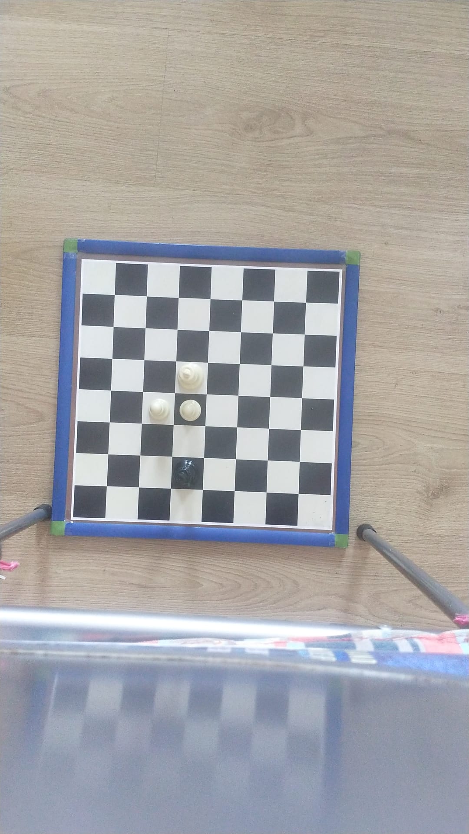
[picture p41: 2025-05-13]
VC/pruebas/prueba (10).jpeg

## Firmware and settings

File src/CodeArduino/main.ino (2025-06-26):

const int dirPin1 = 8;
const int stepPin1 = 9;
const int dirPin2 = 4;
const int stepPin2 = 5;
const int electroimanPin = 7;  // Pin para el electroimán
const int steps = 289;
int stepDelay = 4000;

void setup() {
  Serial.begin(9600); // Inicializa la comunicación serial
  pinMode(dirPin1, OUTPUT);
  pinMode(stepPin1, OUTPUT);
  pinMode(dirPin2, OUTPUT);
  pinMode(stepPin2, OUTPUT);
  pinMode(electroimanPin, OUTPUT); // Configura el pin del electroimán
  digitalWrite(electroimanPin, LOW); // Imán desactivado por defecto
}

void loop() {
  if (Serial.available() > 0) {
    char comando = Serial.read();

    // Control del electroimán
    if (comando == 'e') {
      digitalWrite(electroimanPin, HIGH);  // Activa el imán
      Serial.println("Electroimán ACTIVADO");
    }
    if (comando == 'f') {
      digitalWrite(electroimanPin, LOW);   // Desactiva el imán
      Serial.println("Electroimán DESACTIVADO");
    }

    // Motor 1 adelante
    if (comando == 'a') {
      digitalWrite(dirPin1, HIGH);
      for (int x = 0; x < steps; x++) {
        digitalWrite(stepPin1, HIGH);
        delayMicroseconds(stepDelay);
        digitalWrite(stepPin1, LOW);
        delayMicroseconds(stepDelay);
      }
    }
    // Motor 1 atrás
    if (comando == 'd') {
      digitalWrite(dirPin1, LOW);
      for (int x = 0; x < steps; x++) {
        digitalWrite(stepPin1, HIGH);
        delayMicroseconds(stepDelay);
        digitalWrite(stepPin1, LOW);
        delayMicroseconds(stepDelay);
      }
    }
    // Motor 2 adelante
    if (comando == 'w') {
      digitalWrite(dirPin2, HIGH);
      for (int x = 0; x < steps; x++) {
        digitalWrite(stepPin2, HIGH);
        delayMicroseconds(stepDelay);
        digitalWrite(stepPin2, LOW);
        delayMicroseconds(stepDelay);
      }
    }
    // Motor 2 atrás
    if (comando == 's') {
      digitalWrite(dirPin2, LOW);
      for (int x = 0; x < steps; x++) {
        digitalWrite(stepPin2, HIGH);
        delayMicroseconds(stepDelay);
        digitalWrite(stepPin2, LOW);
        delayMicroseconds(stepDelay);
      }
    }
  }
}

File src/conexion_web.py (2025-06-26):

from flask import Flask, request, jsonify
from flask_cors import CORS  
from modulo_central import movimiento_completo

app = Flask(__name__)
CORS(app)  # ✅ Permite CORS desde cualquier origen

@app.route("/mover", methods=["POST"])
def mover_pieza():
    data = request.get_json()
    movimiento = data.get("movimiento")
    estado_tablero = data.get("estado_tablero")

    if not movimiento or not estado_tablero:
        return jsonify({"error": "Faltan datos"}), 400

    origen = movimiento[:2]
    destino = movimiento[2:4]

    movimiento_completo(estado_tablero, origen, destino)

    return jsonify({"status": "ok", "mensaje": f"Movimiento simulado: {origen} -> {destino}"}), 200

if __name__ == "__main__":
    app.run(port=5000)

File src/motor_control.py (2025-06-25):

import time
import serial

def generar_instrucciones_movimiento(camino):
    """
    Convierte una lista de coordenadas [(fila, col), ...] en instrucciones 'w', 'a', 's', 'd'
    """

    instrucciones = []
    for i in range(1, len(camino)):
        f1, c1 = camino[i - 1]
        f2, c2 = camino[i]

        if f2 < f1:
            instrucciones.append('a')  # izquierda
        elif f2 > f1:
            instrucciones.append('d')  # derecha
        elif c2 > c1:
            instrucciones.append('s')  # bajar
        elif c2 < c1:
            instrucciones.append('w')  # subir
        else:
            raise ValueError(f"Movimiento inválido de {camino[i-1]} a {camino[i]}")

    return instrucciones

def generar_camino_simple(origen, destino):
    """
    Devuelve una lista de coordenadas que forman un camino simple
    de origen a destino en movimientos rectilíneos (primero vertical, luego horizontal).
    """
    camino = [origen]
    fila_origen, col_origen = origen
    fila_destino, col_destino = destino

    # Movimiento vertical
    paso_f = 1 if fila_destino > fila_origen else -1
    for f in range(fila_origen + paso_f, fila_destino + paso_f, paso_f):
        camino.append((f, col_origen))

    # Movimiento horizontal
    paso_c = 1 if col_destino > col_origen else -1
    for c in range(col_origen + paso_c, col_destino + paso_c, paso_c):
        camino.append((fila_destino, c))

    return camino

def enviar_a_robot(letra, arduino):
    arduino.write(letra.encode())

def ejecutar_movimiento_completo(camino_principal, camino_bloqueador=None, origen_robot=(4, 4), delay=0.5):
    """
    Ejecuta uno o dos movimientos encadenados desde una posición de origen.
    - camino_bloqueador: si existe, se mueve primero la pieza que obstruye.
    - camino_principal: movimiento final deseado.
    - origen_robot: casilla base del robot (por defecto e4 = (4, 4))
    """

    arduino = serial.Serial('COM9', 9600)
    time.sleep(2)  # Espera a que se establezca la conexión

    # Función auxiliar para enviar los movimientos de un camino
    def mover(camino, comentario=""):
        if not camino or len(camino) < 2:
            print(f"[ERROR] Camino no válido para {comentario}")
            return camino[-1] if camino else None
        instrucciones = generar_instrucciones_movimiento(camino)
        print(f"[DEBUG] Movimiento ({comentario}): {camino}")
        for letra in instrucciones:
            enviar_a_robot(letra, arduino)
            time.sleep(delay)
        return camino[-1]

    # 1. Movimiento del bloqueador si existe
    if camino_bloqueador:
        # Mover desde origen a la primera casilla del bloqueador
        camino_hacia_bloqueador = generar_camino_simple(origen_robot, camino_bloqueador[0])
        mover(camino_hacia_bloqueador, "hacia bloqueador")

        # Activar electroimán
        enviar_a_robot("e", arduino)

        # Mover el bloqueador
        pos_final_bloqueador = mover(camino_bloqueador, "bloqueador")

        # Desactivar el electroimán
        enviar_a_robot("f", arduino)

        # 2. Movimiento directo a la pieza principal (sin volver al origen)
        camino_hacia_principal = generar_camino_simple(pos_final_bloqueador, camino_principal[0])
        mover(camino_hacia_principal, "hacia principal")

        # Activar electroimán
        enviar_a_robot("e", arduino)

    else:
        # Si no hay bloqueador, ir desde origen a la pieza principal
        camino_hacia_principal = generar_camino_simple(origen_robot, camino_principal[0])
        mover(camino_hacia_principal, "hacia principal")

        # Activar electroimán
        enviar_a_robot("e", arduino)

    # 3. Mover la pieza principal
    pos_final_principal = mover(camino_principal, "pieza principal")

    # Desactivar el electroimán
    enviar_a_robot("f", arduino)

    # 5. Devolver la pieza bloqueadora a su lugar (si existe)
    if camino_bloqueador:
        # Ir desde el origen al lugar temporal del bloqueador
        camino_ir_bloqueador = generar_camino_simple(pos_final_principal, camino_bloqueador[-1])
        mover(camino_ir_bloqueador, "ir a bloqueador temporal")

        # Activar electroimán
        enviar_a_robot("e", arduino)

        # Volver a su posición original
        camino_revertido = list(reversed(camino_bloqueador))
        mover(camino_revertido, "devolver bloqueador")

        # Desactivar el electroimán
        enviar_a_robot("f", arduino)

        # 4. Volver al origen desde la pieza principal
        camino_regreso = generar_camino_simple(camino_bloqueador[0], origen_robot)
        mover(camino_regreso, "regreso al origen")
    else:
        # 4. Volver al origen desde la pieza principal
        camino_regreso = generar_camino_simple(pos_final_principal, origen_robot)
        mover(camino_regreso, "regreso al origen")

    print("[INFO] Movimiento completo realizado.")
    arduino.close()

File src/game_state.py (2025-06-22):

'''
Game State: clase que guarda el estado del tablero.
'''
class GameState:

    '''
    Función de inicialización de las varialbes.
    - board: guarda las posiciones de cada pieza en el tablero
    - current_player: guarda el jugador que le toca mover en el turno actual
    '''
    def __init__(self):
        self.board = [
            ['r', 'n', 'b', 'q', 'k', 'b', 'n', 'r'],
            ['p', 'p', 'p', 'p', 'p', 'p', 'p', 'p'],
            ['.', '.', '.', '.', '.', '.', '.', '.'],
            ['.', '.', '.', '.', '.', '.', '.', '.'],
            ['.', '.', '.', '.', '.', '.', '.', '.'],
            ['.', '.', '.', '.', '.', '.', '.', '.'],
            ['P', 'P', 'P', 'P', 'P', 'P', 'P', 'P'],
            ['R', 'N', 'B', 'Q', 'K', 'B', 'N', 'R']
        ]

        self.current_player = 'white'
    
    '''
    Convierte una posición en nomenclatura de ajedrez a posición x, y del tablero
    - pos: posición en nomencaltura de ajedrez (ej. e4)
    - return x, y: coordenadas de la matriz tablero
    '''
    def chess_to_coords(self, pos):
        x = ord(pos[0]) - ord('a')
        y = 8 - int(pos[1])
        return (x, y)

    '''
    Convierte una posición x, y del tablero a nomenclatura de ajedrez
    - x, y: coordenadas del tablero
    - return pos: posición en nomenclatura de ajedrez
    '''
    def coord_to_chess(self, x, y):
        return f"{chr(ord('a') + x)}{8 - y}"
    
    '''
    Aplica un movimiento a la matriz tablero
    - move: movimiento en noomenclatura uci (ej. "e2e4")
    '''
    def update_board(self, origen, destino):
        x1, y1 = origen
        x2, y2 = destino

        self.board[y2][x2] = self.board[y1][x1]
        self.board[y1][x1] = '.'

    '''
    Comprueva si una posición del tablero esta vacía
    - pos: posición en nomenclatura de ajedrez
    - return: booleano que es true si la posición está vacía y false en caso contrario
    '''
    def is_empty(self, x, y):
        return self.board[y][x] == '.'
    
    # Verifica si una coordenada es válida
    def coordenada_valida(self, x, y):
        return 0 <= x < 8 and 0 <= y < 8
    
    # Devuelve los vecinos (arriba, abajo, izq, der)
    def vecinos(self, x, y):
        for dx, dy in [(-1,0), (1,0), (0,-1), (0,1)]:
            nx, ny = x + dx, y + dy
            if self.coordenada_valida(nx, ny):
                yield nx, ny

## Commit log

2025-05-16 api
    apis creadas de momento
2025-06-22 Solución error con obstáculos
    [game_state.py, modulo_central.py]
2025-06-22 Readme apartado de sofware
2025-06-24 cambio de esquema
